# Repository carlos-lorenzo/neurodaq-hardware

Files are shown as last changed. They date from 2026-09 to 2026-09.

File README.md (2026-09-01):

# neurodaq-hardware

PCBs and mechanical parts for [NeuroDAQ](https://github.com/carlos-lorenzo/neurodaq) —
an open 8-channel wearable EEG headset. Designed in **EasyEDA**; gerbers, drill files,
BOMs and 3D models are committed here, so **both boards are orderable as-is**.

## Boards

### Main carrier (`PCB/main/`)

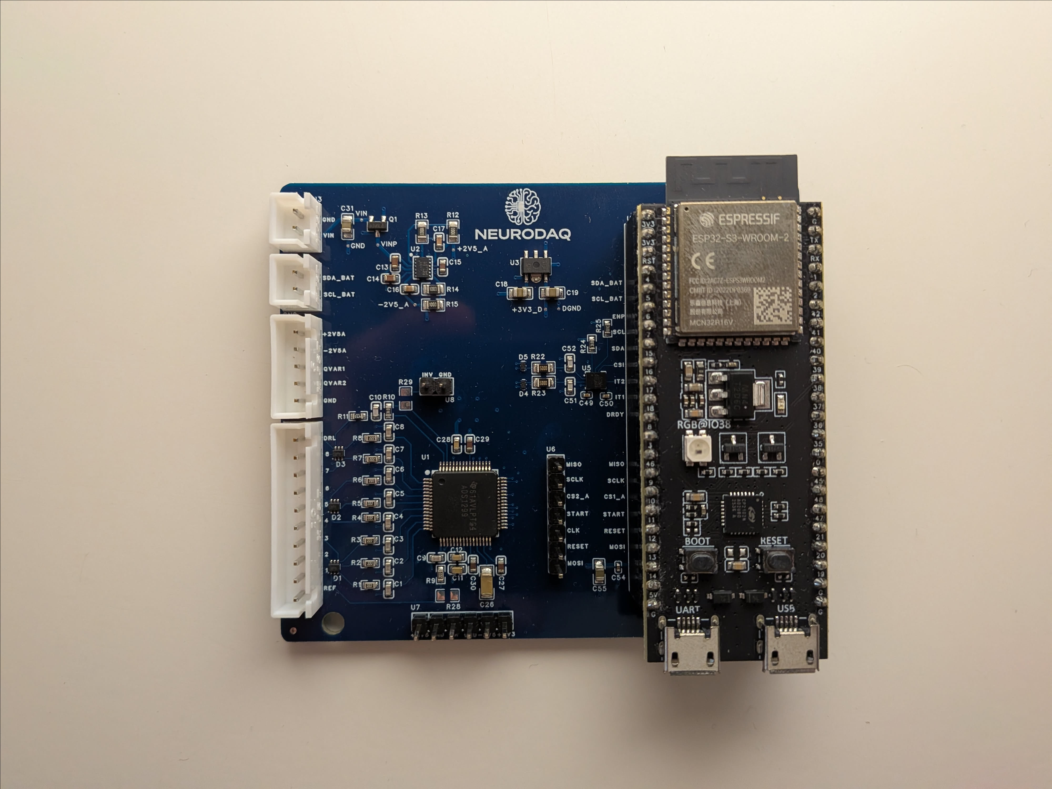
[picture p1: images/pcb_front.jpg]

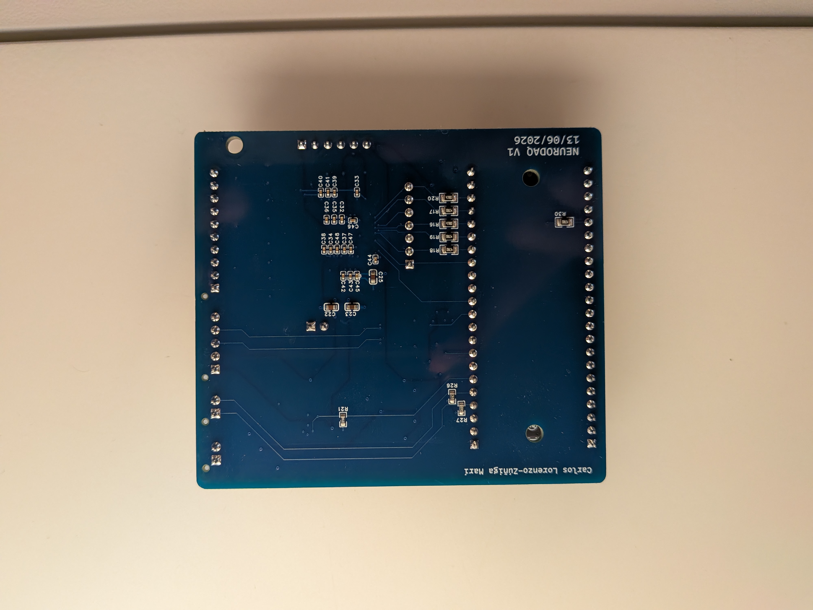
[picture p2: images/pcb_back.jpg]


The analog front-end and MCU carrier. **4-layer** (inner layers present in the gerber
set).

- **ADS1299IPAGR** — 8-channel 24-bit EEG AFE.
- **LM27762** — ±2.5 V analog rails for the AFE.
- **XC6220** — 3.3 V digital rail.
- **LSM6DSV16X** — 6-axis IMU with QVAR (electrostatic sensing).
- Per-channel **2.2 kΩ / 1 nF RC** + ESD protection on each electrode input.
- **DRL / bias drive** for common-mode rejection.
- An **ESP32-S3-DevKitC-1-N8R2** plugs into 2×22 headers — it is *not* soldered, which
  is why no MCU appears in the BOM.
- `CS2_ADC` / GPIO21 is routed for a **second cascaded ADS1299** that is not populated
  (BOM qty 1) and not driven by firmware.

### Breakout (`PCB/breakout/`)

Passive electrode breakout, **2-layer**, top-side assembly only. Brings out E1–E8, REF,
QVAR×2 and GND to two JST XH connectors (10-way + 5-way) that cable to the carrier.

## What's in each PCB folder

| File / dir | Contents |
|---|---|
| `gerbers/` | Gerbers, `.DRL` drill files, flying-probe test JSON, `How-to-order-PCB.txt` |
| `SCH_*.pdf` | Schematic export |
| `BOM_*.xlsx` | Bill of materials |
| `P1.dxf` | Board outline |
| `<board>_3d/` | `.obj` + `.mtl` 3D board model |

> `gerbers/` (EasyEDA's export folder); it is the gerber
> set. To order, follow `How-to-order-PCB.txt` or upload the folder to any fab.

## Mechanical / enclosure

A size-adjustable 3D-printed headset. Author-designed electronics enclosure plus band
and electrode parts adapted from the OpenBCI Ultracortex Mark IV (see Attribution).

| Part | Files | Origin |
|---|---|---|
| `frame_front`, `frame_back_side`, `frame_bottom`, `frame_lid` | DWG + STEP + STL | **Author-designed** electronics enclosure |
| `M4_{Small,Medium,Large}_{Front,Back}`,  | STL | Ultracortex Mark IV |
| `electrode_screw` | DWG + STEP + STL | Ultracortex Mark IV, **modified**: adds studs to melt over and secure a snap connector |

The file-format split is provenance, not oversight: author-designed parts ship editable
DWG + STEP + STL; Mark IV-derived parts are STL-only because that is how they were
obtained.

## Attribution — OpenBCI Ultracortex Mark IV

The band parts (`M4_*`), the wire clip, and the electrode holder derive from the
[OpenBCI Ultracortex Mark IV](https://github.com/OpenBCI/Ultracortex). And are licenced under GPLv3. The relevant files are inside `OpenBCI` subdirectories.

## Still pending

The editable **EasyEDA project export** (`.epro` / JSON) is the one remaining gap.
Everything needed to *fabricate* is here; what's missing is what you'd need to *modify*
the schematic/layout. Will upload soon. For now here's the [link]( https://oshwlab.com/clorzui/project_mbmhksrb).

## Licence

MIT for the boards and author-designed parts — **except** the OpenBCI-derived
mechanical parts; see [Attribution](#attribution--openbci-ultracortex-mark-iv).

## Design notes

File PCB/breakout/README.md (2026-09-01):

# Breakout PCB

Passive electrode breakout for NeuroDAQ. Routes the scalp electrodes and reference to
two JST XH connectors that cable to the main carrier.

- **Layers:** 2.
- **Assembly:** top side only.
- **Active components:** none — this board is passive.

## Signals

Brings out **E1–E8**, **REF**, **QVAR ×2**, and **GND**, split across two JST XH
connectors:

- **10-way JST XH:** the eight channels + REF + GND.
- **5-way JST XH:** QVAR ×2 + GND (+ spare).

> The exact pin-by-pin mapping and cable keying should be documented here with the
> connector part numbers — it's the one fact that makes the boards buildable by someone
> other than the author, and a miswire puts DC on an electrode. Add it from the EasyEDA
> schematic before public release.

## Files

`gerbers/` (gerbers + drill + flying-probe JSON), `SCH_Breakout_*.pdf`,
`BOM_Breakout_*.xlsx`, `P1.dxf` (outline), `breakout_3d/` (3D model).

## Status

Fabricated. Editable EasyEDA source export pending.

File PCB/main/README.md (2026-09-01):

# Main carrier PCB

The analog front-end and MCU carrier for NeuroDAQ.

- **Layers:** 4 (signal / GND / PWR / signal — inner layers `Gerber_InnerLayer1.G1`,
  `Gerber_InnerLayer2.G2` present).
- **Assembly:** both sides (top + bottom paste layers present).

## Key components

| Ref | Part | Role |
|---|---|---|
| AFE | ADS1299IPAGR | 8-channel 24-bit ΔΣ EEG front-end |
| — | LM27762 | ±2.5 V analog rails (AVDD/AVSS) |
| — | XC6220 | 3.3 V digital LDO |
| IMU | LSM6DSV16X | 6-axis + QVAR |
| MCU | ESP32-S3-DevKitC-1-N8R2 | Plugs into 2×22 headers (not soldered) |

## Front end

Each of the 8 channels has a 2.2 kΩ / 1 nF RC + ESD network on its input (ESD/RF
protection; the ADS1299's internal decimation does the anti-aliasing). SRB1 referential
topology; DRL bias drive for common-mode rejection.

`EN_AP` / GPIO6 gates the LM27762 analog rail; firmware asserts it and waits ~250 ms
for the rails to settle before configuring the AFE.

## Connectors

Two JST XH headers cable to the breakout: a 10-way (E1–E8, REF, GND) and a 5-way
(QVAR ×2, GND, …). Full pin assignment lives with the breakout board — see
`../breakout/README.md`.

## Files

`gerbers/` (gerbers + drill + flying-probe JSON), `SCH_Neurodaq_*.pdf`,
`BOM_Neurodaq_*.xlsx`, `P1.dxf` (outline), `neurodaq_3d/` (3D model). To order, follow
`gerbers/How-to-order-PCB.txt`.

## Status

Fabricated and bring-up tested. Editable EasyEDA source export pending.

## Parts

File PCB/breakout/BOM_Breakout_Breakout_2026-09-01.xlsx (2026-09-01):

No. | Quantity | Comment | Designator | Footprint | Value | Manufacturer Part | Manufacturer | Supplier Part | Supplier
1 | 1 | B10B-XH-AM(LF)(SN) | CN1 | CONN-TH_B10B-XH-AM-LF-SN |  | B10B-XH-AM(LF)(SN) | JST | C495726 | LCSC
2 | 1 | B5B-XH-AM(LF)(SN) | CN2 | CONN-TH_B5B-XH-AM-LF-SN |  | B5B-XH-AM(LF)(SN) | JST | C161872 | LCSC

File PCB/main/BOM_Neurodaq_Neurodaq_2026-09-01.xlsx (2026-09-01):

No. | Quantity | Comment | Designator | Footprint | Value | Manufacturer Part | Manufacturer | Supplier Part | Supplier
1 | 9 | 1nF | C1,C2,C3,C4,C5,C6,C7,C8,C9 | C0603 | 1nF | 0603CG102F500NT | FH(风华) | C507408 | LCSC
2 | 1 | 1.5nF | C10 | C0603 | 1.5nF | GRM1885C1H152FA01D | muRata(村田) | C710892 | LCSC
3 | 1 | 10uF | C11 | C0603 | 10uF | GRM188R61A106KE69D | muRata(村田) | C77044 | LCSC
4 | 2 | 100nF | C12,C28 | C0603 | 100nF | CGA0603X7R104K500JT | HRE(芯声) | C6119867 | LCSC
5 | 2 | 4.7uF | C13,C14 | C0603 | 4.7uF | GRM188Z71C475KE21D | muRata(村田) | C389010 | LCSC
6 | 1 | 470nF | C15 | C0603 | 470nF | CC0603KRX7R9BB474 | YAGEO(国巨) | C513577 | LCSC
7 | 2 | 2.2uF | C16,C17 | C0603 | 2.2uF | CL10A225KA8NNNC | SAMSUNG(三星) | C57895 | LCSC
8 | 4 | 10uF | C18,C19,C31,C55 | C0805 | 10uF | CGA0805X5R106K500MT | HRE(芯声) | C6119889 | LCSC
9 | 6 | 1uF | C22,C23,C25,C27,C29,C30 | C0603 | 1uF | CGA0603X5R105K500JT | HRE(芯声) | C6119852 | LCSC
10 | 1 | 100uF | C26 | C1206 | 100uF | GRM31CR60J107KE39L | muRata(村田) | C782156 | LCSC
11 | 20 | 100nF | C32,C33,C34,C35,C36,C37,C38,C39,C40,C41,C42,C43,C44,C45,C46,C47,C48,C49,C50,C54 | C0402 | 100nF | CC0402JRX7R7BB104 | YAGEO(国巨) | C541464 | LCSC
12 | 2 | 110pF | C51,C52 | C0603 | 110pF | CC0603FRNPO9BN111 | YAGEO(国巨) | C519568 | LCSC
13 | 1 | B10B-XH-AM(LF)(SN) | CN1 | CONN-TH_B10B-XH-AM-LF-SN |  | B10B-XH-AM(LF)(SN) | JST | C495726 | LCSC
14 | 1 | B5B-XH-AM(LF)(SN) | CN2 | CONN-TH_B5B-XH-AM-LF-SN |  | B5B-XH-AM(LF)(SN) | JST | C161872 | LCSC
15 | 2 | B2B-XH-AM(LF)(SN) | CN3,CN4 | CONN-TH_B2B-XH-AM-LF-SN |  | B2B-XH-AM(LF)(SN) | JST | C161869 | LCSC
16 | 3 | TPD4E1B06DRLR | D1,D2,D3 | SOT-5X3_L1.6-W1.2-P0.50-LS1.6-TL |  | TPD4E1B06DRLR | TI(德州仪器) | C1972953 | LCSC
17 | 2 | ESDALCL5-1BM2 | D4,D5 | SOD-882_L1.0-W0.6-BI |  | ESDALCL5-1BM2 | ST(意法半导体) | C1974942 | LCSC
18 | 1 | DMG2305UX | Q1 | SOT-23-3_L2.9-W1.3-P0.95-LS2.4-BR-1 |  | DMG2305UX | TECH PUBLIC(台舟) | C2940629 | LCSC
19 | 9 | 2.2kΩ | R1,R2,R3,R4,R5,R6,R7,R8,R9 | R0603 | 2.2kΩ | PTFR0603B2K20N9 | RESI(开步睿思) | C2692837 | LCSC
20 | 1 | 1MΩ | R10 | R0603 | 1MΩ | FRC0603F1004TS | FOJAN(富捷) | C2907003 | LCSC
21 | 1 | 47kΩ | R11 | R0603 | 47kΩ | FRC0603F4702TS | FOJAN(富捷) | C2907042 | LCSC
22 | 4 | 100kΩ | R12,R13,R14,R15 | R0805 | 100kΩ | 0805W8F1003T5E | UNI-ROYAL(厚声) | C149504 | LCSC
23 | 6 | 47Ω | R16,R17,R18,R19,R20,R30 | R0805 | 47Ω | RC0805FR-0747RL | YAGEO(国巨) | C114541 | LCSC
24 | 1 | 100Ω | R21 | R0603 | 100Ω | FRC0603F1000TS | FOJAN(富捷) | C2906981 | LCSC
25 | 2 | 500Ω | R22,R23 | R0805 | 500Ω | ARG05BTC5000 | Viking(光颉) | C2828711 | LCSC
26 | 4 | 10kΩ | R24,R25,R26,R27 | R0603 | 10kΩ | FRH0603B1002TS | FOJAN(富捷) | C5126214 | LCSC
27 | 1 | ADS1299IPAGR | U1 | TQFP-64_L10.0-W10.0-P0.50-LS12.0-TL |  | ADS1299IPAGR | TI(德州仪器) | C476817 | LCSC
28 | 1 | LM27762DSST | U2 | WSON-12_L2.0-W3.0-P0.50-BL-EP |  | LM27762DSST | TI(德州仪器) | C134018 | LCSC
29 | 1 | XC6220B331PR-G | U3 | SOT-89-5_L4.5-W2.5-P1.50-LS4.4-BR |  | XC6220B331PR-G | TOREX(特瑞仕) | C3013658 | LCSC
30 | 1 | LSM6DSV16XTR | U5 | LGA-14_L3.0-W2.5-P0.50-BR |  | LSM6DSV16XTR | ST(意法半导体) | C5267406 | LCSC
31 | 1 | HB-PH3-25417PB2GOP | U6 | HDR-TH_7P-P2.54-V-M |  | HB-PH3-25417PB2GOP | HANBO(汉博) | C6332200 | LCSC
32 | 1 | HDGCPH-PZ01-06 | U7 | HDR-TH_6P-P2.54-V-M |  | HDGCPH-PZ01-06 | HDGC(华德共创) | C19190972 | LCSC
33 | 1 | HX PZ2.54-1x2P ZZ | U8 | HDR-TH_2P-P2.54-V-M-3 |  | HX PZ2.54-1x2P ZZ | hanxia(韩下) | C32713268 | LCSC
34 | 2 | ZX-PM2.54-1-22PY | U9,U10 | HDR-TH_22P-P2.54-V-F |  | ZX-PM2.54-1-22PY | Megastar(兆星) | C7499337 | LCSC

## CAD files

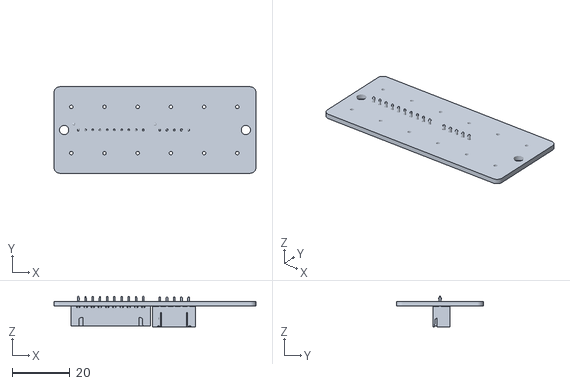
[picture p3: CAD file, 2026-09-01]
PCB/breakout/breakout_3d/breakout_3d.obj
70.0 x 30.0 x 10.6

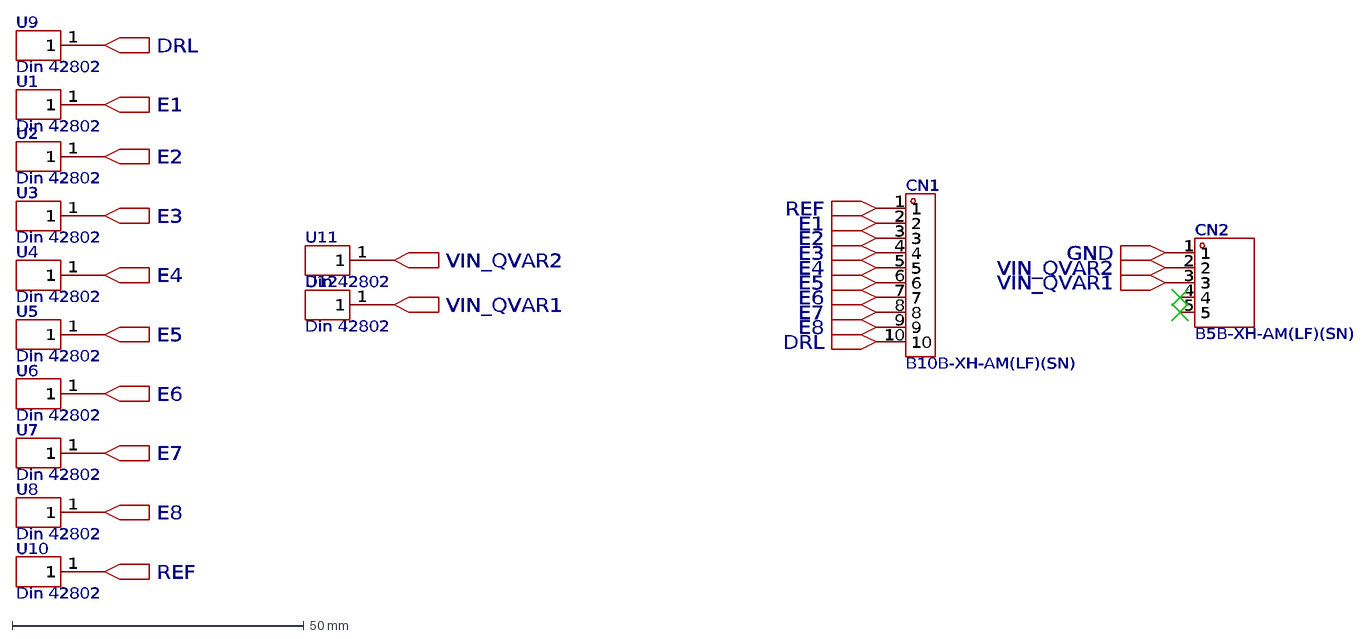
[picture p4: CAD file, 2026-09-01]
PCB/breakout/P1.dxf
Din 42802
U9
1
U1
U2
U3
U4
U5
U6
U7
U8
U10
CN1
B10B-XH-AM(LF)(SN)
2
3
4
5
6
7
8
9
10
DRL
E1
E2
E3
E4
E5
E6
E7
E8
REF
U11
U12
VIN_QVAR2
VIN_QVAR1
CN2
B5B-XH-AM(LF)(SN)
GND

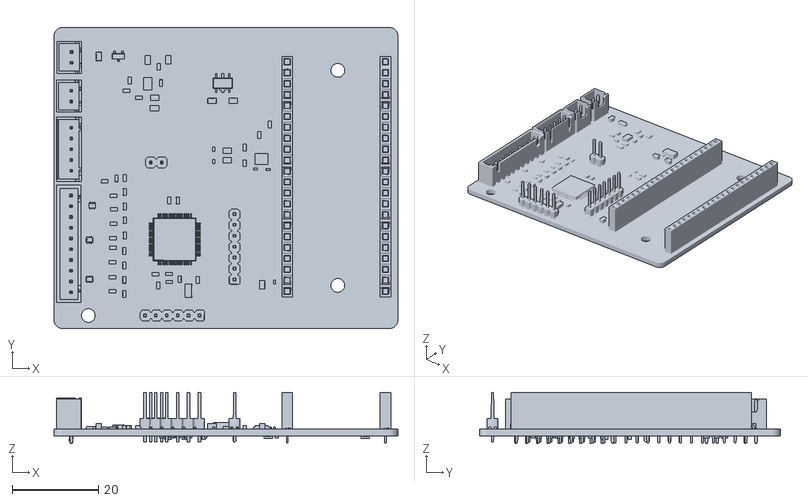
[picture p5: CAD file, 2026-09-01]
PCB/main/neurodaq_3d/neurodaq_3d.obj
80.0 x 70.0 x 12.0

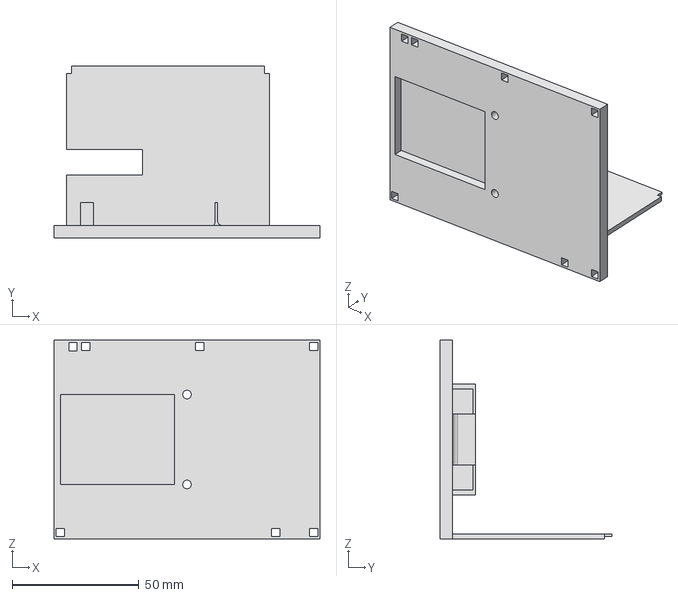
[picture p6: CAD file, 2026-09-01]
STEP/frame_bottom.stp
105.0 x 68.0 x 78.5 mm

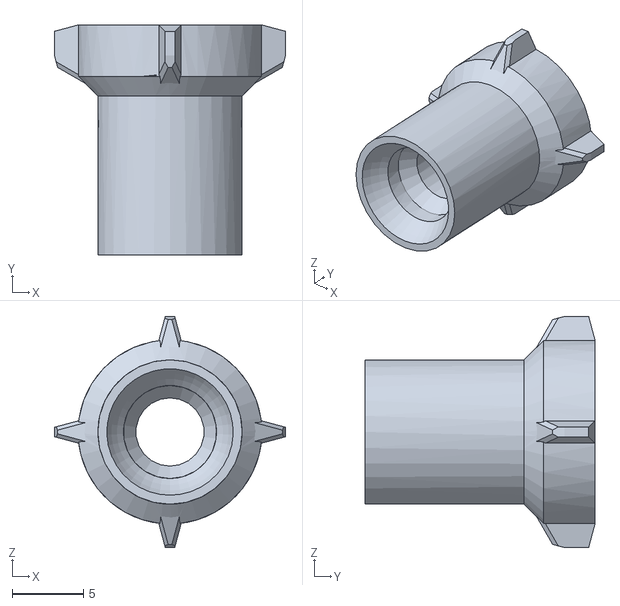
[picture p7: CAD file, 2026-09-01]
STL/OpenBCI/electrode_holder.stl
16.3 x 16.2 x 16.3

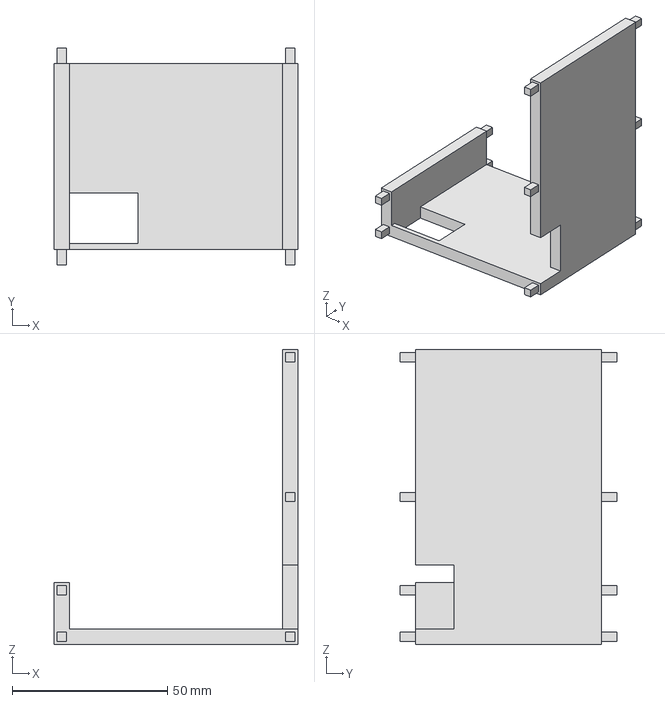
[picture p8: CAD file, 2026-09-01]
STEP/frame_back_side.stp
78.5 x 70.0 x 95.0 mm

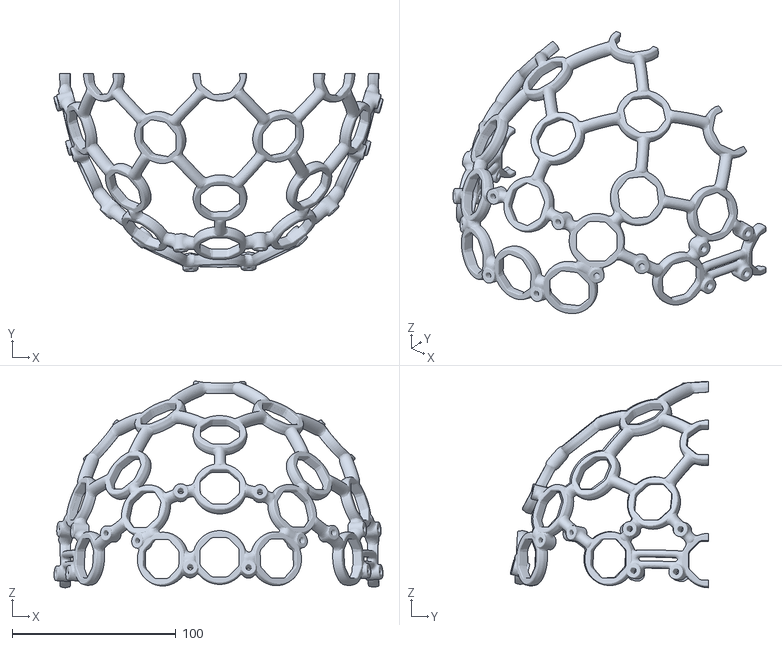
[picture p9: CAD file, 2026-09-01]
STL/OpenBCI/M4_Medium_Front.stl
201.0 x 121.2 x 126.2

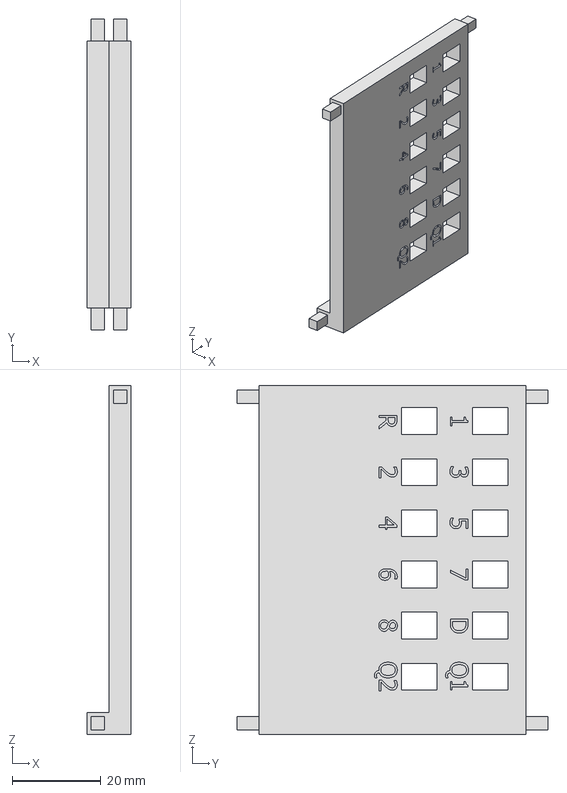
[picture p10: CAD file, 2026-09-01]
STEP/frame_front.stp
10.0 x 70.0 x 78.5 mm

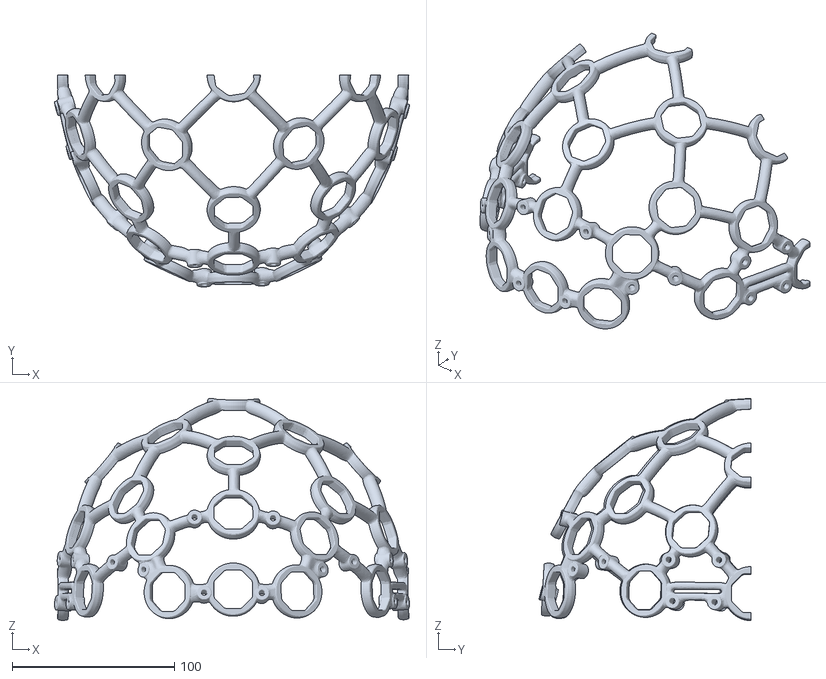
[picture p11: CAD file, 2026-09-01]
STL/OpenBCI/M4_Large_Front.stl
219.0 x 130.8 x 137.1

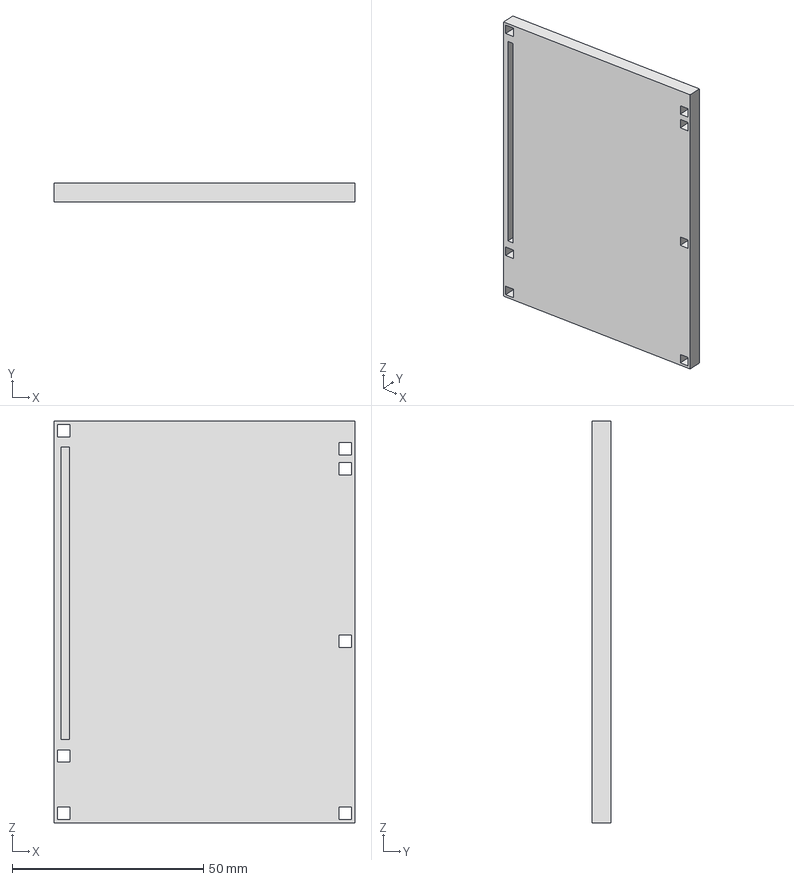
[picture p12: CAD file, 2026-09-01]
STEP/frame_lid.stp
78.5 x 5.00 x 105.0 mm

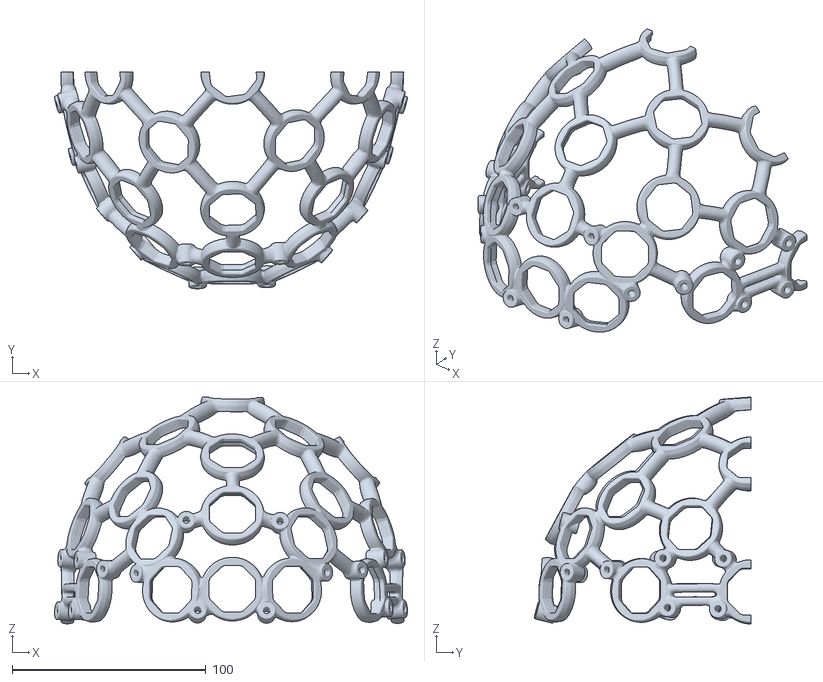
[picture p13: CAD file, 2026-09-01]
STL/OpenBCI/M4_Small_Front.stl
182.0 x 111.8 x 117.0

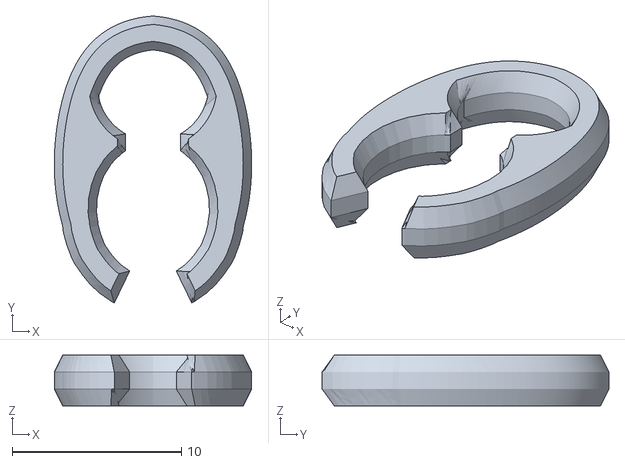
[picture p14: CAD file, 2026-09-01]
STL/OpenBCI/M4_Wire_Clip.stl
11.7 x 17.0 x 3.00

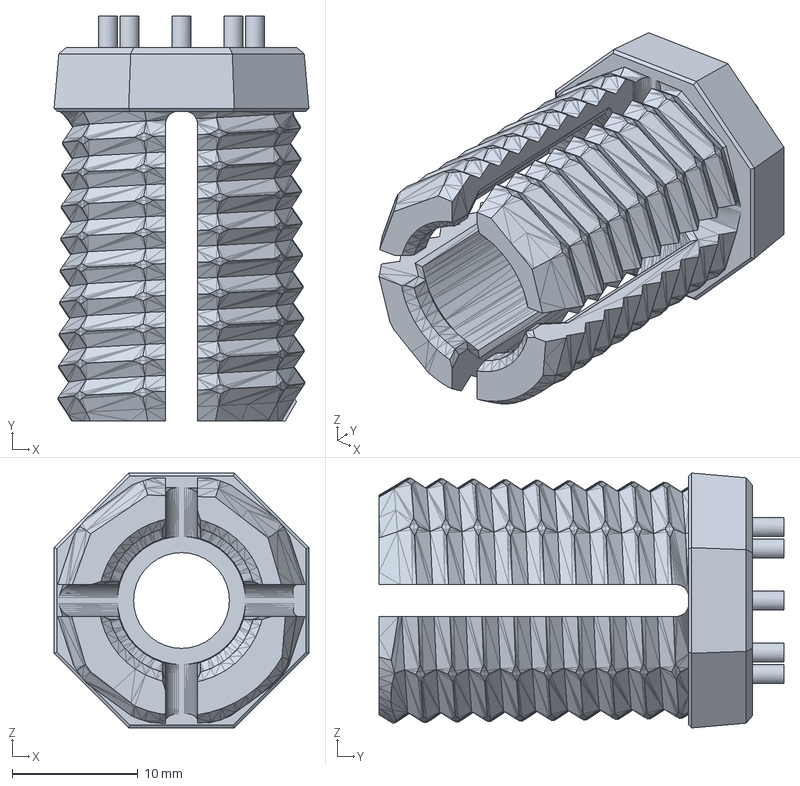
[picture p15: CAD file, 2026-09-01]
STEP/OpenBCI/electrode_screw.stp
20.3 x 32.2 x 20.3 mm

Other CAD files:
PCB/main/P1.dxf
STL/OpenBCI/M4_Medium_Back.stl
STL/OpenBCI/M4_Small_Back.stl
STL/OpenBCI/M4_Large_Back.stl
DWG/electrode_screw.dwg
DWG/frame_back_side.dwg
DWG/frame_bottom.dwg
DWG/frame_front.dwg
DWG/frame_lid.dwg
STL/OpenBCI/electrode_screw.stl
STL/frame_back_side.stl
STL/frame_bottom.stl
STL/frame_front.stl
STL/frame_lid.stl

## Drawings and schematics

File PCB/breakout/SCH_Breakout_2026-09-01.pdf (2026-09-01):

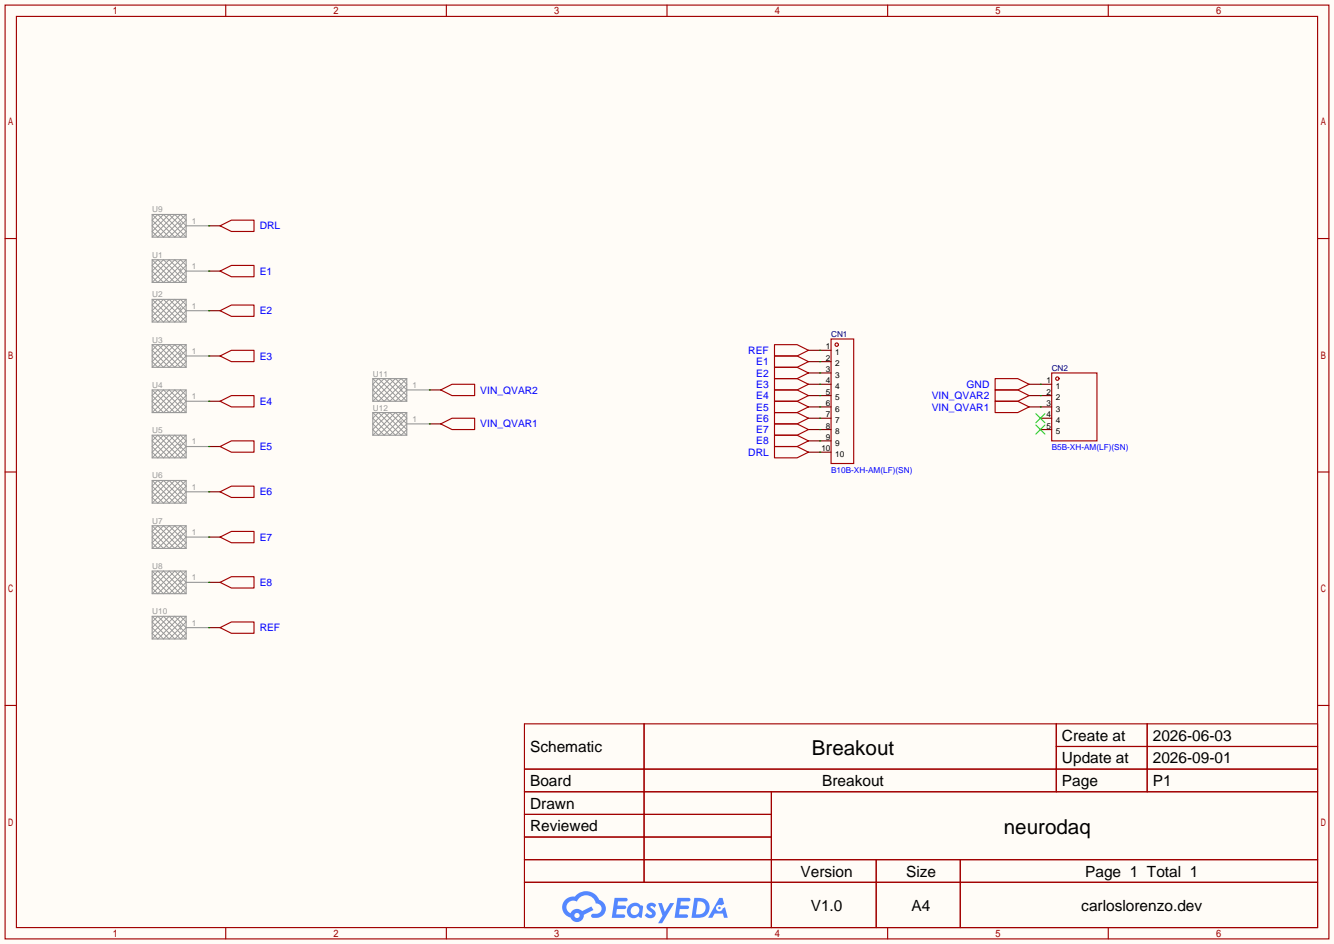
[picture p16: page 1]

Schematic | Breakout | Create at | 2026-06-03

Update at | 2026-09-01

Board | Breakout | Page | P1
Drawn | | neurodaq
Reviewed

Version | Size | Page 1 Total 1
V1.0 | A4 | carloslorenzo.dev

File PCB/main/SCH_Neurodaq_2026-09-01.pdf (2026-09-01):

POWER | IMU & QVAR

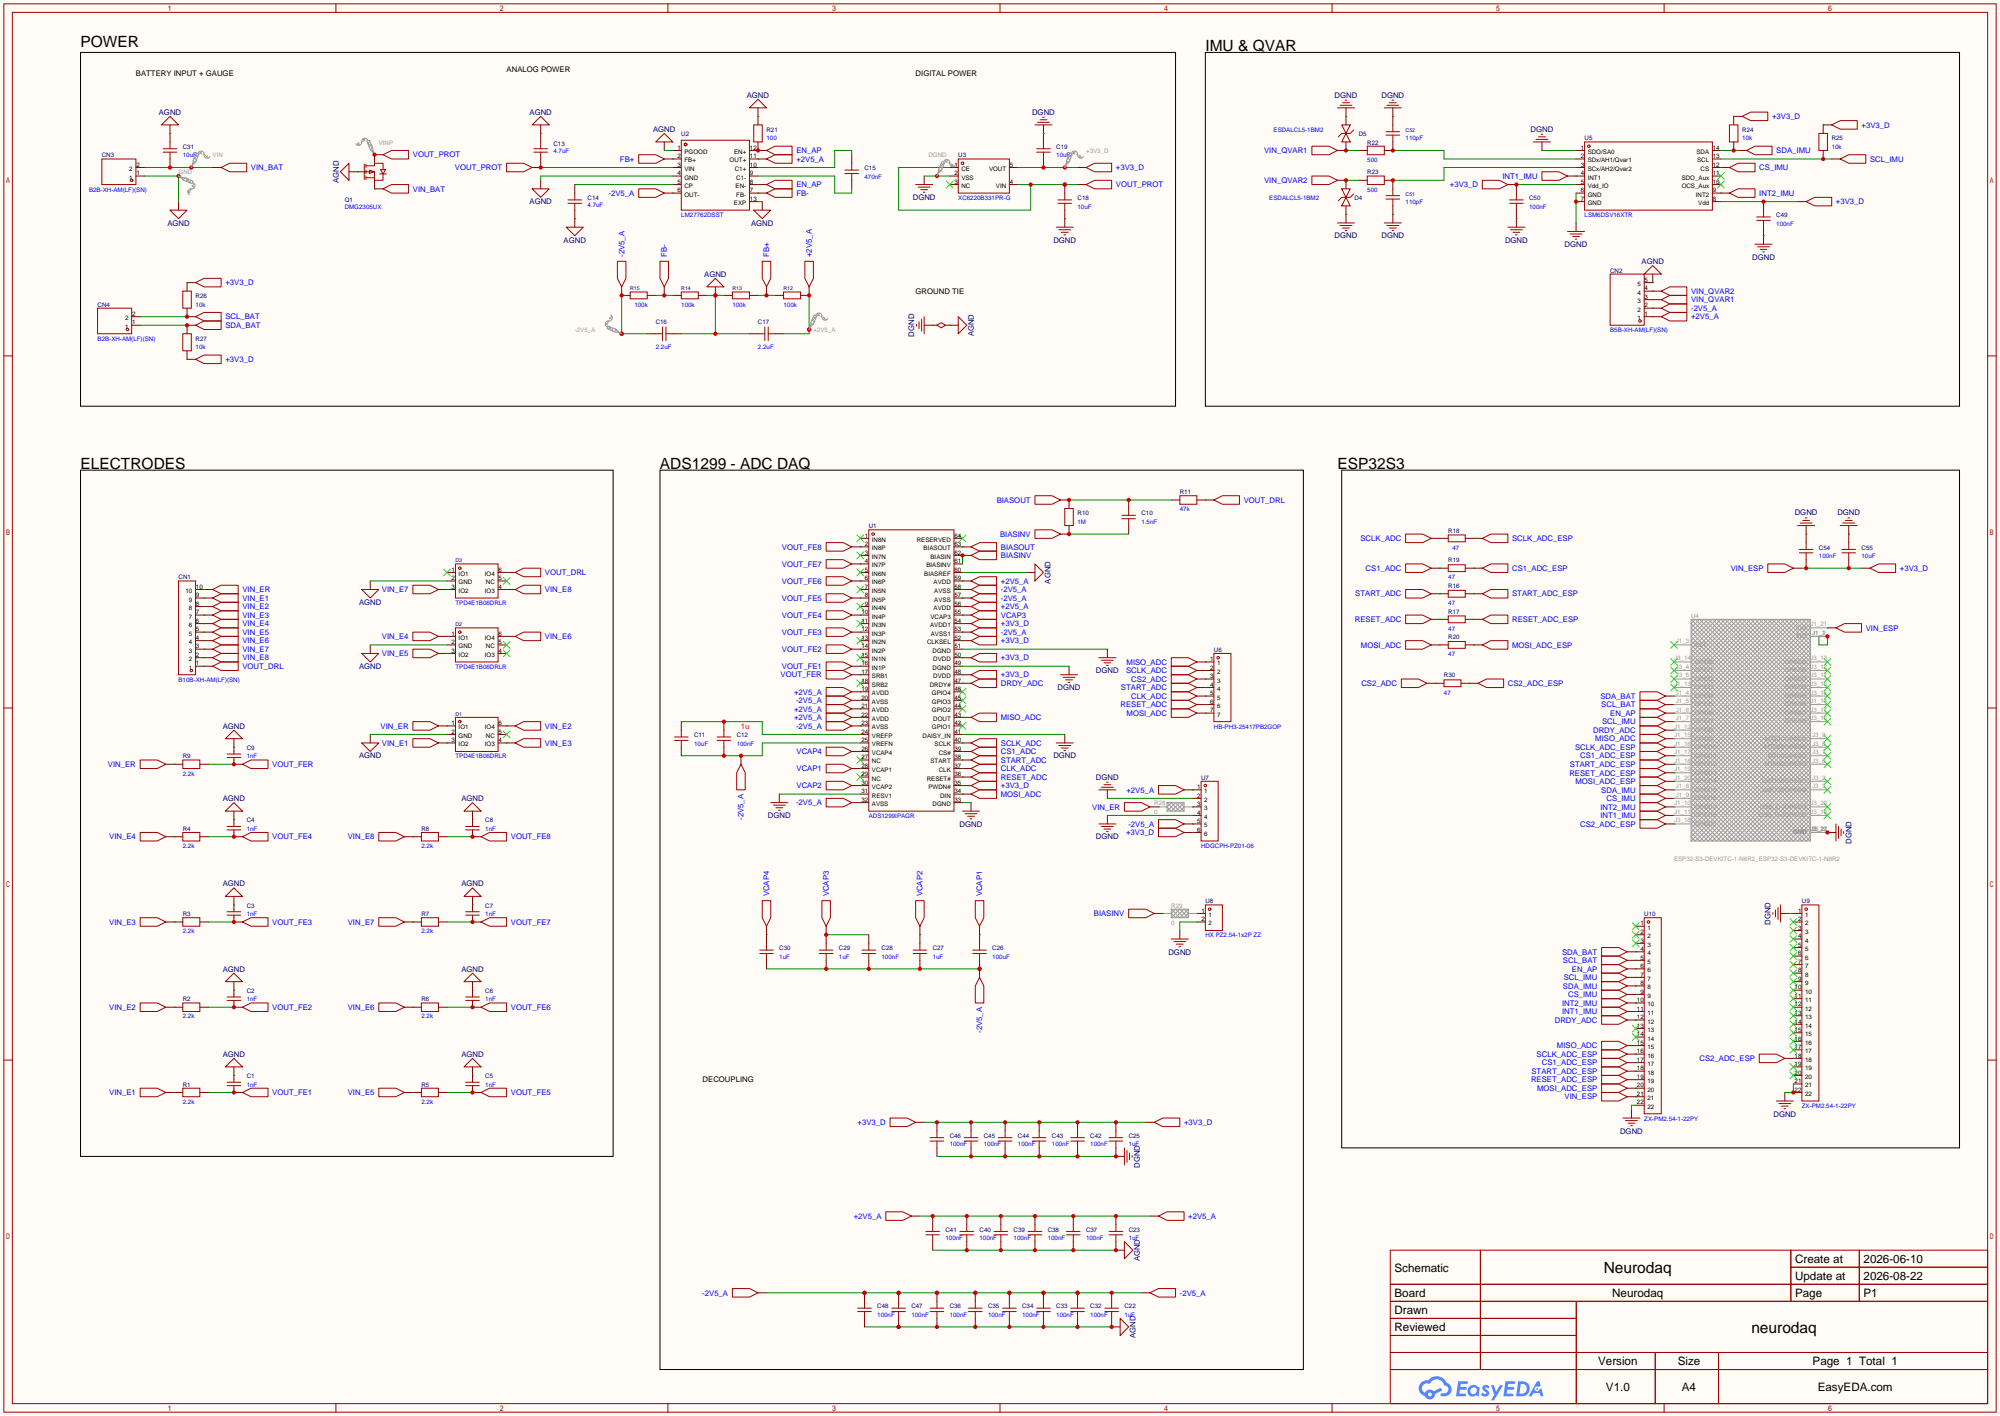
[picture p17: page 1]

Schematic | Neurodaq | Create at | 2026-06-10

Update at | 2026-08-22

Board | Neurodaq | Page | P1
Drawn | | neurodaq
Reviewed

Version | Size | Page 1 Total 1
V1.0 | A4 | EasyEDA.com

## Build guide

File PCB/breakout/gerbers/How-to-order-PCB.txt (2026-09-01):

How to Order PCB

Please refer to:
https://prodocs.easyeda.com/en/pcb/order-order-pcb/index.html

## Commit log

2026-09-01 included pcb files
    [BOM_Breakout_Breakout_2026-09-01.xlsx, BOM_Neurodaq_Neurodaq_2026-09-01.xlsx, P1.dxf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]
2026-09-01 included gebbers and 3d
    [Drill_NPTH_Through.DRL, Drill_PTH_Through.DRL, Drill_PTH_Through_Via.DRL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]
2026-09-01 Phase 0: Add initial .gitignore to untrack local PCB/EasyEDA cruft
2026-09-01 Rewrite hardware README + fill PCB READMEs; add OpenBCI Mark IV attribution
2026-09-01 included images and gerbers
    [Drill_NPTH_Through.DRL, Drill_PTH_Through.DRL, Drill_PTH_Through_Via.DRL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]
2026-09-16 updated schematic and gerbers with power fix
2026-10-25 shield schematic done
